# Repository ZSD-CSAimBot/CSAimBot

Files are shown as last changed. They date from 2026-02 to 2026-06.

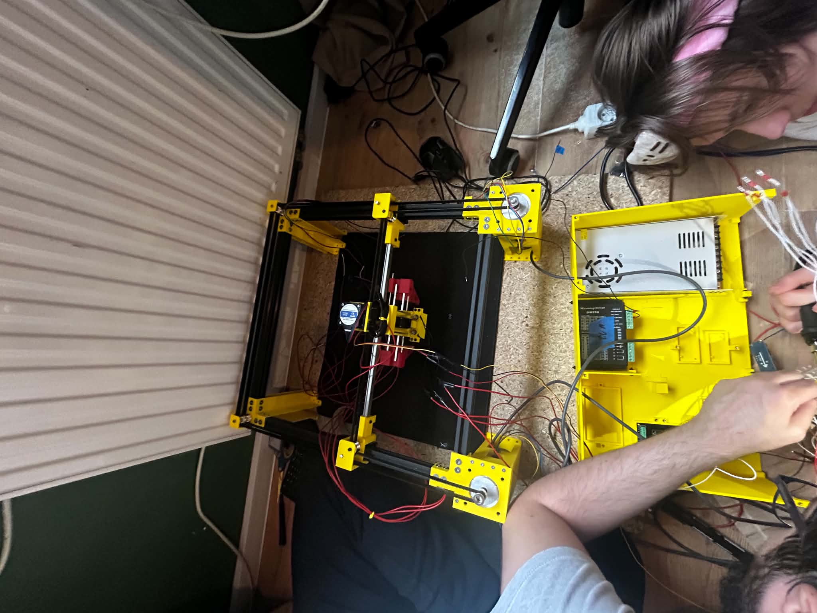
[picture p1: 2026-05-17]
docs/assembly_media/05.15/5d69896e-32a7-49aa-bc5d-4ff8ce60f4f2.jpg

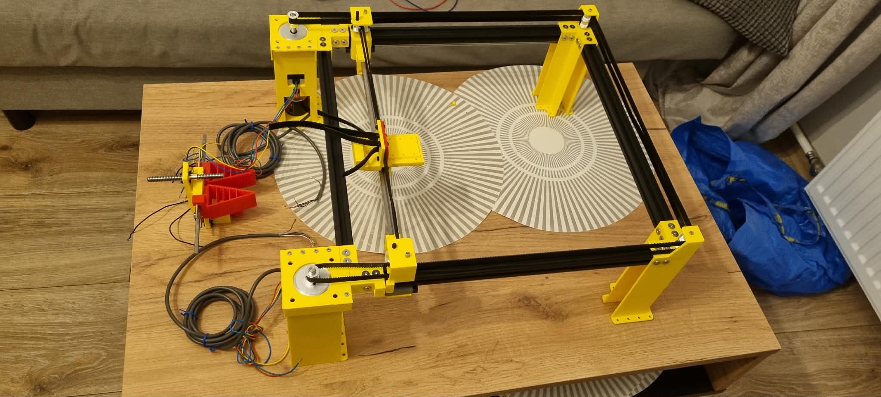
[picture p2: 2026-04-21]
docs/assembly_media/04.11/2.jpg

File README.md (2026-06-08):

# CSAimBot [CSBot]

---

## Brief Project Description
The goal of the project is to create a physical AimBot for the game CS:GO. The program would read the game screen, mark enemies, and return the value by which the mouse must move. To execute the mouse movement, a Cartesian robot with an appropriate grip will be created. The robot would be able to adapt to different mice and DPI values. The robot will be capable of shooting and compensating for weapon recoil, ensuring greater accuracy. The player would control the movement using the WASD keys, so the robot must cooperate with them.

---

## Functional Scope
* Reading the screen and marking enemies.
* Calculating the robot's trajectory.
* Moving the mouse using the Cartesian robot and shooting via a button.
* Looking around if no enemies are detected.
* Cooperating with the player.

---

## System Architecture
* **Robot moving the mouse:** A Cartesian robot featuring stepper motors and encoders or servomechanisms for the XY axes, and a ball/trapezoidal lead screw for the Z axis, equipped with a proper grip capable of holding multiple types of mice. The robot would correct the steering if the crosshair fails to land on the enemy and would compensate for weapon recoil.
* **Screen capture system:** Screen capture will be handled using appropriate Python/C++ libraries, forwarding the captured frames to the enemy detection algorithm.
* **Enemy detection system:** A YOLO-based system will detect and mark enemies on the image, returning values that allow controlling the robot's motors in order to aim at and eliminate the target.

---

## Technology Stack

**Hardware - robot:**
* ESP32 microcontroller, motor drivers.
* NEMA 23 stepper motors, ball/trapezoidal lead screw.
* Power supply, step-down converters.
* 3D printed robot arm and gripper, servo to operate the gripper.

**Hardware - PC:**
* PC with a graphics card, monitor, mouse, keyboard.

**Software:**
* Python/C/C++ languages and relevant libraries, YOLO.
* PyCharm, Arduino IDE, VSC.
* Serial communication (e.g., UART, TCP/IP, USB).
* Inverse kinematics algorithms.

---

## Main Assumptions

### Hardware Assumptions
* The project will operate at room temperature in an enclosed room on a horizontal, flat surface that allows for the proper mounting of the robot (e.g., a desk) and the proper use of the keyboard.
* The mouse will move on a cloth mousepad.
* The mouse must use a laser or optical sensor and have at least 2 buttons (left and right); the remaining buttons will be ignored. 
* When changing the mouse or DPI values, a semi-automatic calibration procedure will be executed. The robot will check the distance it needs to move to transition between reference points on a dedicated map.
* PC-to-Microcontroller communication will be handled via UART (USB) at a baud rate of 115200.

### Software Assumptions
* The computer program will run on Windows 11 Pro build >=25H2 or equivalent. The program will not work on Linux or macOS.
* A PC with adequate computing power is required (a graphics card supporting CUDA, min. RTX 3060) along with a monitor; laptops are not supported.
* The program will detect enemy models in the game (it will distinguish CT models from T models).
* The program will detect whether the user is holding a pistol or a rifle using classic computer vision (template matching with OpenCV). If the player is holding a pistol or a sniper rifle, recoil compensation will be disabled. Otherwise, the program will correct the recoil for specific weapons (AK47/M4A1).

### Game Assumptions
* The program will only run during an active round, on any map.
* The game must run at a minimum of 60 FPS. Enabling the option for instant corpse removal after a kill in a local game is required.
* The reaction time, with the eDPI adjusted so that the robot does not need to lift the mouse, will be at most equal to the reaction time of a skilled player (<200ms).

---

## Project Team
* Tomasz Nazar
* Filip Pietrzak
* Patryk Polechoński
* Hubert Czarnecki
* Karol Puczyński
* Piotr Rokita
* Łukasz Mroczek
* Antoni Sulkowski
* Andrzej Placek
* Łukasz Orluk

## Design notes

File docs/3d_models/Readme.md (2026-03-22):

Nagrywanie_2026-03-15_012706

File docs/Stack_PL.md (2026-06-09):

# Stack Technologiczny

<h2>Software</h2>

- PyCharm >=2025.3.2
- Visual Studio Code >=1.108
- Arduino IDE >=2.3.5
- Python >=3.12
- YOLO26
- Docker + ROS image
- GitHub + Git
- CS:GO - oficjalna wersja legacy
- Autodesk Fusion
- Gazebo
- Bambu Studio

<h2>Hardware</h2>

- Esp32
- 2x silniki NEMA 23
- 3x sterowniki silników krokowych DM556
- Prowadnice
- Szyny
- Śruba kulowa/trapezowa
- Silnik NEMA 17
- Solenoid
- Logic level converter 3.3V -> 5V
- Zasilacz 36V 10A
- Filament TPU
- Filament PLA/PETG
- Kable
- Nvidia RTX 3060

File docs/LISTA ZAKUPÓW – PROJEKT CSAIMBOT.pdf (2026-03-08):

LISTA ZAKUPÓW – PROJEKT CSAIMBOT

I. MECHANIKA
- Szyna liniowa MGN12 z wózkiem (40 cm) – 2 szt.
- Szyna liniowa MGN12 z wózkiem (50 cm) – 1 szt.
- Profil aluminiowy T-slot 2020 (40 cm) – 4 szt.
- Narożniki aluminiowe (wersja 20) – 10 szt.
- Pas zębaty GT2 (5 m, 10 mm szerokości) – 1 szt.
- Rolki zębate GT2 – 6 szt.
- Rolki gładkie GT2 – 2 szt.
- Zębatki napędowe na wał silnika 8 mm – 2 szt.
- Śruba trapezowa osi Z (skok 2 mm, 10 cm) – 1 szt.
- Sprzęgło 8x5 mm – 1 szt.
- Pręt stalowy 3 mm (długość 330 mm) – 2 szt.
- Filament (TPU, 1,75mm, 1 kg) – 1 szt.

II. SILNIKI I STEROWNIKI

- Silnik krokowy Nema 23 (dwustronny wał 8 mm) – 2 szt.
- Silnik krokowy Nema 17 "Pancake" – 1 szt.
- Sterownik cyfrowy DM556 – 3 szt.
- Enkoder obrotowy E6B2-CWZ6C (600 P/R) – 2 szt.

III. CHWYTAK I KLIKANIE

- Serwo MG996R (180 stopni) – 1 szt.
- Zębatka serwa 25T (Moduł 0.5) – 1 szt.
- Listwa zębata (Moduł 0.5, 5x5x300mm) – 1 szt.
- Solenoidy 12V – 2 szt.

IV. ELEKTRONIKA I STEROWANIE

- Mikrokontroler ESP32 – 1 szt.
- Konwerter poziomów logicznych TXS0108E (8-kanałowy) – 1 szt.

- Przetwornica LM2596 ADJ (Regulowana) – 2 szt.
V. ZASILANIE
- Zasilacz (36V, 10A, 360W) – 1 szt.

Wszystkie elementy wymienione w powyższym zestawieniu zostały już zakupione i opłacone.

- Wiele pozycji na liście zostało zamówionych w ilościach większych, niż wynika to z bezpośrednich potrzeb konstrukcyjnych. Wynika to z charakteru pakowania tych elementów, co jednocześnie zapewnia nam zapas w razie awarii lub błędów montażowych.
- Zamówienia zostały rozdzielone pomiędzy różnych dostawców w celu optymalizacji kosztów oraz dostępności. Wykorzystano platformy: Temu, AliExpress, Allegro oraz Poltech.
- Łączny koszt wszystkich podzespołów mechanicznych, napędowych oraz elektronicznych wraz z dostawą wyniósł 1415,50 zł.

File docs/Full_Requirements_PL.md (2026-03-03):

# Zakres funkcjonalny
- Czytanie ekranu
- Oznaczanie przeciwników
- Obliczanie drogi robota
- Ruch myszką za pomocą robota kartezjańskiego
- Strzał za pomocą przycisku
- Rozglądanie się w przypadku braku wykrycia przeciwników
- Współpraca z graczem
- Symulacja robota przez ROS i Gazebo

# Szczegółowe założenia

<h3>Hardware'owe</h3>

- Projekt będzie działać w temperaturze pokojowej w zamkniętym pomieszczeniu na jednolitej poziomej płaskiej powierzchni umożliwiającej poprawne zamontowanie robota (np. biurko) i umożliwiającej poprawne użycie klawiatury.
- Robot będzie rozmiarów umożliwiających swobodne sterowanie myszką i wygodnie sterowanie klawiaturą przez użytkownika na jednym stanowisku.
- Mysz, będzie się poruszać na materiałowej podkładce do myszy.
- Komputer i robot, będą pobierały zasilanie z sieci 230V. Dalsze etapy zasilania (np. zasilacz komputerowy), realizowane w zależności od zastosowanego sprzętu.
- Wszystkie komponenty muszą być sprawne, aby projekt działał poprawnie.
- Pozycja silników krokowych będzie odczytywana z enkoderów podłączonych w odpowiedni sposób do silników.
- Mysz użyta do projektu powinna być bezprzewodowa lub powinna mieć kabel o długości zapewniającej swobodną pracę robota.
- Sterowanie robotem będzie odbywać się WYŁĄCZNIE za pomocą klawiatury i/lub myszki oraz dedykowanych przycisków przy robocie
- Mysz musi posiadać przynajmniej 2 przyciski - lewy i prawy przycisk, reszta przycisków będzie ignorowana.
- Mysz musi korzystać z laserowego lub optycznego sensora. Nie może być to mysz kulkowa. Mysz nie może mieć znacznie wystających niestandardowych elementów.
- Przy zmianie myszki/wartości DPI na inną wykonywana będzie półautomatyczna procedura kalibracji. Robot będzie sprawdzał o ile musi się poruszyć, żeby przejść między punktami referencyjnymi na specjalnej mapie.
- Klawiatura będzie obsługiwana przez jednego użytkownika, steruje poruszaniem się postacią klawiszami WSAD
- Projekt nie będzie obsługiwać komend głosowych ani wizji maszynowej do poleceń.
- Chwytak będzie zamykany serwomechanizmem
- Mysz będzie trzymana siłą tarcia
- Mysz pod chwytakiem robota umieszcza użytkownik w miejscu do tego przeznaczonym (centrum podkładki).
- Nastawy robota będą mogły być zmienione w przypadku poluzowania się części lub wykrycia innych nieprawidłowości.
- Gracz ma do dyspozycji przycisk zatrzymania robota.
- Komunikacja PC-Mikrokontroler poprzez UART (USB) z prędkością 115200 baud
- Przyciski myszy będą naciskane solenoidami lub szybkimi serwomechanizmami.
- Mysz musi mieć klawisze (lewy i prawy) równoległe do powierzchni na której stoi robot. Nie obsługiwane będą myszy typu Logitech MX Vertical itp. 
- Akceleracja wskaźnika myszy jest wyłączona.
- Elementy robota oprócz silników, szyn, sterowników, prowadnic, śrub, zębatek, pasów itp. będą wydrukowane 3d

<h3>Software'owe</h3>

- Program komputerowy będzie działać na systemie Windows 11 Pro build >=25H2 lub równoważnym systemie Windows. Program nie będzie działać na Linuxie ani na MacOS.
- Stworzony zostanie własny dataset do wykrywania przeciwników oraz rodzaju trzymanej broni
- Program będzie działać na komputerze PC o odpowiedniej mocy obliczeniowej (min. karta graficzna RTX 3060) z monitorem - nie na laptopie. Na laptopie może nie zostać spełniony warunek czasu reakcji.
- Program będzie wykrywać modele przeciwników w grze. (Będzie odróżniał modele CT od T)
- Program będzie współpracować z CS:GO w wersji umożliwiającej dodanie botów lub graczy do gry.
- Program będzie komunikował się z robotem za pomocą połączenia przewodowego.
- Program będzie przystosowany do działania lokalnie na komputerze na którym zostanie zainstalowany.
- Ewentualny interfejs użytkownika będzie zrealizowany w języku angielskim.
- Jeśli gracz trzyma pistolet lub karabin snajperski to kompensacja odrzutu będzie wyłączona. W przeciwnym wypadku program będzie korygował odrzut konkretnych broni (AK47/M4A1).
- Podczas celowania z karabinu snajperskiego wykrywani zostaną tylko wrogowie znajdujący się w polu widzenia lunety. Włączeniem / Wyłączeniem przybliżenia steruje użytkownik z klawiatury.
- Użytkownik będzie używał praworęcznego modelu broni.
- Robot będzie strzelał pojedynczymi strzałami lub seriami w zależności od ustawienia gracza. Odrzut będzie kompensowany jedynie przy strzelaniu seriami.
- Program będzie działał z grą ustawioną na minimum 60 FPS.
- Okno wykrywania będzie miało rozmiar 1280x736
- Robot będzie miał 100% celności w cele statyczne.
- Robot będzie miał 60% celności w cele poruszające się.
- Trenowanie YOLO - na komputerze 
- Rozdzielczość 1080p
- ROS obsługiwany za pomocą Dockera i WSL2 na Windows

<h3>Związane z grą</h3>

- Program będzie działał tylko podczas rozpoczętej rundy.
- Program będzie działał na dowolnej oficjalnej mapie CS:GO
- Program będzie działał z włączoną opcją natychmiastowego usuwania ciał po zabójstwie w grze lokalnej
- W przypadku wykrycia kilku celów, program wybiera cel najbliżej aktualnej pozycji celownika
- Czas reakcji przy eDPI dobranym tak, aby robot nie musiał podnosić myszy będzie wynosił maksymalnie tyle ile czas reakcji dobrego gracza (<200ms) Czasem reakcji nazywamy czas po którym robot zaczyna kierować mysz w stronę przeciwnika od jego pojawienia się na ekranie.
- Viewmodel będzie ustawiony tak aby było go widać w obszarze przechwytywania

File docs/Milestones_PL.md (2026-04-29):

# Milestones

---

## Milestone 1: Wstępny model i projekt sprzętowy
### M1 - Software (Wykrywanie w YOLO):

* **Cel**: Przetwarzanie obrazu i lokalizacja przeciwników na ekranie, komunikacja z mikrokontrolerem.

* **Mierzalny wskaźnik**: Średnia precyzja, szybkość przetwarzania (FPS) oraz rozmiar datasetu.

* **Dataset / Sposób pomiaru**: Ewaluacja na zbiorze testowym złożonym ze screenów z gry na różnych mapach z użyciem wbudowanych skryptów YOLO. Prędkość mierzona podczas gry lokalnej.

* **Warunek przejścia dalej**: Skuteczność YOLO > 80% dla wykrywania modeli CT/T, stałe utrzymanie min. 60 FPS w czasie inferencji na karcie RTX 3060, dataset o rozmiarze min 5000 zdjęć.

### M1 - Hardware (Projekt CAD):

* **Cel**: Zaprojektowanie robota kartezjańskiego zdolnego do przemieszczania i podnoszenia myszki oraz przygotowanie kosztorysu

* **Mierzalny wskaźnik**: Osiągalna przestrzeń robocza oraz teoretyczny luz mechaniczny.

* **Sposób pomiaru**: Symulacja kinematyki i pomiary w programie typu CAD (np. Autodesk Fusion).

* **Warunek przejścia dalej**: Projekt pozwala na pełne pokrycie wirtualnej podkładki o wymiarach min. 30x30 cm, podniesienie uchwytu z myszką w osi Z na wysokość gwarantującą brak odczytu sensora oraz zakupienie części.
---

## Milestone 2: Konstrukcja i sterowanie ręczne
### M2 - Software (Aplikacja i integracja wejścia):

* **Cel**: Aplikacja PC czytająca klawiaturę i wysyłająca komendy do mikrokontrolera, symulacja w Gazebo, kompensacja odrzutu broni.

* **Mierzalny wskaźnik**:Opóźnienie przesyłu danych (Latency) na linii PC -> Mikrokontroler. Rozmiar datasetu oraz skuteczność Yolo. 

* **Sposób pomiaru**: Analiza logów z timestampami wysłania paczki danych oraz potwierdzenia jej odbioru przez UART (115200 baud).

* **Warunek przejścia dalej**: Skuteczność YOLO > 95%, opóźnienie wysłania pakietu poniżej 5 ms i ~0% zgubionych ramek na dystansie 10 tysięcy prób, dataset o rozmiarze min 10000 zdjęć. 

### M2 - Hardware (Fizyczny robot):

* **Cel**: Budowa fizycznego robota i weryfikacja poprawności sterowania silnikami z poziomu aplikacji.

* **Mierzalny wskaźnik**: Czas reakcji mechaniki na komendę.

* **Sposób pomiaru**: Nagranie w zwolnionym tempie od momentu wciśnięcia przycisku klawiatury do rozpoczęcia ruchu silnika krokowego/serwa.

* **Warunek przejścia dalej**: Wydrukowane elementy 3D, reakcja silników i fizyczne poruszenie myszką. Czas reakcji<200ms.
---

## Milestone 3: Pełna integracja (Auto-Aim i kalibracja)
### M3 - Software + Hardware:

* **Cel**: Integracja całego systemu: YOLO podaje koordynaty, algorytm przelicza je na kroki, a robot fizycznie namierza i strzela.

* **Mierzalny wskaźnik**: Całkowity czas reakcji układu, celność strzału oraz skuteczność wykrywania broni po stronie gracza.

* **Sposób pomiaru**: Testy na lokalnym serwerze treningowym (np. Aim Botz). Mierzenie poprzez analizę nagrania z rozgrywki.

* **Warunki przejścia dalej**:

* Całkowity czas reakcji układu (Wykrycie -> Ruch) wynosi < 200 ms.

* Dokładność namierzania stojącego celu 100%.

* Półautomatyczna procedura kalibracji eDPI/myszki działa poprawnie.

* System poprawnie włącza/wyłącza kompensację odrzutu na podstawie trzymanej broni (AK47/M4A1 vs Pistolet/Snajperka).

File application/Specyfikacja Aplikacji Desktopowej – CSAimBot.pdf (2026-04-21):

# Specyfikacja Aplikacji Desktopowej – CSAimBot

## 1. Wymagania Funkcjonalne Aplikacji

a. Moduł Komunikacji

Moduł ten odpowiada za ustanowienie, utrzymanie i monitorowanie stabilnego, dwukierunkowego połączenia między komputerem PC a mikrokontrolerem zarządzającym sprzętem, a także za obsługę środowiska symulacyjnego:

- Nawiązywanie Połączenia
- Wygląd (UI): Główny przycisk "Połącz / Rozłącz", inicjujący komunikację. Etykieta przycisku zmienia się dynamicznie w zależności od aktualnego stanu.
- Zasada działania (Backend): Po wciśnięciu przycisku otwierana jest komunikacja PC-Mikrokontroler poprzez UART (USB). Następuje utworzenie połączenia między komputerem, a mikrokontrolerem. W tle realizowana jest procedura nawiązywania połączenia – aplikacja PC wysyła ramkę testową (np. INIT_CSBOT), a mikrokontroler musi odpowiedzieć z góry zdefiniowanym potwierdzeniem. Zabezpiecza to przed przypadkowym wysłaniem komend ruchu do innego urządzenia podpiętego pod USB.
- Status Połączenia i Monitorowanie Logów
- Wygląd (UI): Wizualny wskaźnik (np. dioda LED w interfejsie: Zielona = połączono, Czerwona = błąd) informujący o poprawnym połączeniu lub błędzie.
- Zasada działania (Backend): Obsługa komunikacji działa w osobnym wątku aplikacji (tzw. Thread/Worker), aby nasłuchiwanie na porcie nie blokowało interfejsu graficznego użytkownika.
- Przełącznik Trybu Pracy (Fizyczny / Symulacja)
- Wygląd (UI): Przełącznik typu Toggle lub osobne zakładki pozwalające wybrać między pracą na fizycznym urządzeniu ("Tryb Sprzętowy") a symulacją ("Tryb ROS").
- Zasada działania (Backend): Moduł obsługuje komunikację Windows -> ROS na dockerze. Po aktywacji tego trybu, wyliczone z systemu wizyjnego wektory ruchu nie są wysyłane na port UART, lecz przekierowywane (np. poprzez protokół TCP/UDP) do kontenera, co pozwala na symulację robota w Gazebo. Środowisko to wspiera również pełny obieg danych, włączając w to komunikację ROS->(Windows)->Robot, jeśli wymagana będzie integracja sprzętowa w pętli symulacji.

b. Moduł Kalibracji i Diagnostyki

Sekcja niezbędna do przygotowania robota do pracy z różnymi modelami myszy i ustawieniami systemowymi:

- Bazowanie (Homing):
- Wygląd (UI): Przycisk "Bazuj robota (HOME)". Obok znajdują się kontrolki stanu osi X oraz Y (np. czerwone ikony zmieniające się na zielone po udanym bazowaniu) oraz tekstowe wyświetlanie aktualnych współrzędnych maszynowych.
- Flow użytkownika: Po uruchomieniu urządzenia użytkownik musi kliknąć ten przycisk, zanim podejmie jakąkolwiek inną akcję. Opcjonalnie program może wymuszać tę akcję przy każdym nowym połączeniu z portem szeregowym.
- Zasada działania (Backend): Po wciśnięciu przycisku aplikacja wysyła dedykowaną ramkę danych (np. komendę HOME) przez UART do mikrokontrolera. Mikrokontroler zaczyna podawać impulsy na sterowniki silników krokowych osi X i Y, wymuszając ruch wózka w kierunku punktu zerowego. Następnie wysyłany jest sygnał przerwania (interrupt) do mikrokontrolera, który natychmiast zatrzymuje silniki i przypisuje tej pozycji wartość X=0, Y=0. Od tego momentu aplikacja wie, gdzie znajduje się środek podkładki i jaki jest maksymalny bezpieczny zakres ruchu.
- Kalibracja DPI:
- Wygląd (UI): Przycisk "Rozpocznij Kalibrację".
- Flow użytkownika: Uruchamiana jest specjalna mapa w CS:GO z punktami referencyjnymi. Użytkownik ustawia mysz na środku obszaru roboczego i uruchamia proces.
- Zasada działania (Backend): Algorytm musi ustalić relację między fizycznym ruchem myszy a ruchem celownika na ekranie. Robot będzie sprawdzał, o ile musi się poruszyć, żeby przejść między punktami referencyjnymi na specjalnej mapie. W tym celu przewidujemy wykorzystanie dokładnie trzech stałych punktów referencyjnych (np. tworzących trójkąt w przestrzeni gry). Aplikacja wysyła do robota rozkaz przesunięcia się w stronę każdego z tych punktów o ściśle określoną, znaną odległość (np. określoną liczbę kroków silnika). Robot wykonuje ruch, a następnie system wizyjny przechwytujący ekran analizuje przesunięcie celownika względem tych trzech punktów. Wiedząc, o ile kroków obróciły się silniki w obu osiach podczas przejścia między poszczególnymi punktami i o ile pikseli przesunął się obraz, aplikacja oblicza bardzo precyzyjny współczynnik proporcjonalności. Dzięki temu podczas właściwej gry, gdy YOLO wykryje głowę przeciwnika w odległości 60 pikseli, aplikacja błyskawicznie przeliczy to na konkretną liczbę kroków do wysłania do sterowników silników.

- Mapa kalibracyjna:

Komenda w terminalu dla CSGO:

steam.exe -applaunch 730 +map nazwa_mapy -insecure

- -applaunch 730: Informuje Steama, że chcemy włączyć CS:GO.
- +map nazwa_mapy: Zmusza grę do natychmiastowego załadowania konkretnej mapy z folderu csgo/maps/ z pominięciem głównego menu.
- -insecure: Uruchamia grę bez ochrony VAC (Valve Anti-Cheat). Blokuje ona możliwość wejścia na serwery publiczne, eliminując ryzyko nałożenia blokady na konto użytkownika podczas testów.

Użycie wbudowanej biblioteki subprocess, która będzie podłączona z przyciskiem "Rozpocznij Kalibrację" w aplikacji.

Kod windows:

import subprocess
import os

def uruchom_kalibracje():
steam_path = r"C:\Program Files (x86)\Steam\steam.exe" map_name = "aimbot_calibration_map"

command = [
steam_path,
"-applaunch", "730", | # ID gry
"+map", map_name, | # Załaduj mapę
"-insecure", | # Wyłącz VAC
"-windowed", "-w", "1920", "-h", "1080" # Wymuś okno i rozdzielczość ]

try:
print("Uruchamianie CS:GO z mapą kalibracyjną...") subprocess.Popen(command)
except Exception as e:
print(f"Błąd podczas uruchamiania: {e}")

### 2. Kod w Pythonie (Wersja Linux)

import subprocess

def uruchom_kalibracje_linux():
map_name = "aimbot_calibration_map"

command = [
"steam",
"-applaunch", "730", | # ID gry
"+map", map_name, | # Załaduj mapę
"-insecure", | # Wyłącz VAC
"-windowed", "-w", "1920", "-h", "1080" # Wymuś okno i rozdzielczość ]

try:
print("Uruchamianie CS:GO na Linuxie z mapą kalibracyjną...") subprocess.Popen(command)
except FileNotFoundError:
print("Błąd: Nie znaleziono wykonywalnego pliku 'steam'.") except Exception as e:
print(f"Błąd podczas uruchamiania: {e}")
- Test chwytaka i klikacza:
- Wygląd (UI): Panel diagnostyczny zawierający przyciski "Zaciśnij / Zwolnij Chwytak" oraz przyciski wyzwalające lewy (LPM) i prawy (PPM) przycisk myszy. Warto dodać suwak do precyzyjnej regulacji siły docisku, aby nie zgnieść obudowy myszki.
- Flow użytkownika: Użytkownik wykorzystuje ten panel do wstępnego ustawienia robota po umieszczeniu nowej myszki.
- Zasada działania (Backend):
a) Chwytak: Aplikacja wysyła docelową wartość wychylenia. Mikrokontroler przekłada tę wartość na sygnał PWM (Pulse Width Modulation) o odpowiednim wypełnieniu, wysyłany do serwomechanizmu. Serwo obraca orczyk, zamykając wydrukowany z TPU chwytak, który utrzymuje mysz siłą tarcia.
b) Klikacz: Zgodnie ze specyfikacją, do naciskania klawiszy użyte będą solenoidy. Po kliknięciu "Test LPM" w aplikacji, program wysyła krótką komendę uderzenia. Mikrokontroler wysyła pojedynczy, bardzo krótki impuls prądowy na cewkę solenoidu. Pole magnetyczne błyskawicznie wypycha rdzeń z odpowiednią siłą, fizycznie wciskając przycisk myszy leżącej pod robotem, po czym rdzeń wraca do pozycji spoczynkowej.
c. Moduł Bezpieczeństwa

Ten moduł odpowiada za ochronę sprzętu (robota, komputera i urządzeń peryferyjnych) przed uszkodzeniami mechanicznymi oraz za zachowanie kontroli użytkownika nad pracą urządzenia w sytuacjach awaryjnych.

- Awaryjne Zatrzymanie (E-Stop)
- Wygląd (UI): Czerwony przycisk "E-STOP / ZATRZYMAJ". Dodatkowo, w ustawieniach aplikacji musi istnieć możliwość przypisania globalnego skrótu klawiszowego (np. Spacja lub Escape), który zadziała nawet wtedy, gdy aplikacja zminimalizowana jest w tle podczas gry w CS:GO.
- Flow użytkownika: Gracz ma do dyspozycji przycisk zatrzymania robota. W przypadku nagłego, niekontrolowanego ruchu ramienia lub zablokowania mechanizmu, gracz uderza w zaprogramowany klawisz. Robot natychmiast zatrzymuje się w miejscu, a w aplikacji pojawia się komunikat o trybie awaryjnym.
- Zasada działania (Backend): Aplikacja wymusza natychmiastowe wysłanie priorytetowej ramki danych (np. komendy HALT) przez interfejs UART. Mikrokontroler odbiera tę komendę jako przerwanie o najwyższym priorytecie. Logika sprzętowa natychmiast przestaje generować sygnały krokowe (STEP/DIR) dla sterowników silników. Dodatkowo, mikrokontroler wysyła sygnał dezaktywujący (np. pin ENABLE na sterownikach silników krokowych), co zdejmuje moment trzymający z cewek silników. Dzięki temu wózek osi X/Y traci sztywność i gracz może bezpiecznie, ręcznie odsunąć ramię robota od myszki bez ryzyka uszkodzenia napędów.
- Monitorowanie Integralności i Zgubionych Kroków - opcjonalne
- Wygląd (UI): Panel wskaźników statusu (np. zielone/czerwone kropki) dla każdej osi z osobna (X, Y, Z). W razie awarii pojawia się pop-up z dokładnym kodem błędu (np. Błąd pozycjonowania osi X - zablokowany wózek). W panelu znajduje się również dostęp do zmiany parametrów robota.
- Flow użytkownika: Jeśli podczas pracy robot nagle uderzy w przeszkodę i zgubi kroki, aplikacja automatycznie przerwie jego pracę, aby nie pogorszyć sytuacji. Nastawy robota będą mogły być zmienione w przypadku poluzowania się części lub wykrycia innych nieprawidłowości. Użytkownik musi wtedy zweryfikować stan mechaniczny, dokręcić elementy i przeprowadzić ponowne bazowanie.
- Zasada działania (Backend): Algorytm opiera się na sprzężeniu zwrotnym z układu napędowego. Pozycja silników krokowych będzie odczytywana z enkoderów podłączonych w odpowiedni sposób do silników. Mikrokontroler nieustannie porównuje zadaną pozycję z faktyczną. Jeśli różnica między tymi wartościami przekroczy bezpieczny próg błędu, system wnioskuje, że wystąpiła fizyczna blokada lub przeciążenie. Aplikacja natychmiast uruchamia procedurę E-Stop, ponieważ wszystkie komponenty muszą być sprawne, aby projekt działał poprawnie.
d. Moduł Statystyk i Monitorowania

Sekcja analityczna pełni rolę narzędzia diagnostycznego oraz walidacyjnego. Jej głównym zadaniem jest ciągłe zbieranie danych telemetrycznych i wizyjnych w celu weryfikacji, czy fizyczny układ (robot + system wizyjny) spełnia rygorystyczne założenia projektowe dotyczące czasu reakcji i celności:

- Monitorowanie Czasu Reakcji
- Wygląd (UI): Dynamiczny wykres liniowy (odświeżany w czasie rzeczywistym) pokazujący opóźnienia w milisekundach. Obok wykresu znajdują się liczniki: "Aktualny czas reakcji", "Średni czas reakcji" oraz wskaźnik wizualny (np. zielony/czerwony), który zapala się na czerwono, gdy opóźnienie przekroczy założone w projekcie maksimum (<200 ms).
- Flow użytkownika: Użytkownik nie musi aktywnie ingerować w ten panel podczas gry. Po zakończeniu rundy lub meczu może wejść w tę zakładkę, aby sprawdzić czas reakcji.
- Zasada działania (Backend): Aplikacja precyzyjnie loguje znaczniki czasu (timestamps) w trzech kluczowych momentach trwania pętli sterowania:
a) T1 (Detekcja): Moment, w którym algorytm YOLO z sukcesem zidentyfikuje przeciwnika (bounding box) i zaklasyfikuje go jako priorytet (np. najbliżej celownika).
b) T2 (Transmisja): Moment wysłania przeliczonego wektora ruchu przez port UART do mikrokontrolera.
c) T3 (Akcja sprzętowa): Moment odebrania przez PC sprzętowego potwierdzenia od mikrokontrolera, że pierwsze impulsy zostały wysłane na sterowniki silników.
Całkowity czas reakcji układu to różnica między T3 i T1. Aplikacja uśrednia te wyniki, by zniwelować błędy pomiarowe.
- Skuteczność i Celność
- Wygląd (UI): Panel w formie "Dashboardu" zawierający wskaźniki procentowe (np. wykresy). Podzielony na dwie główne kategorie: "Celność – Cele Statyczne" oraz "Celność – Cele Poruszające się". Widoczny jest też ogólny licznik oddanych strzałów do strzałów trafionych.
- Flow użytkownika: Gracz może przeglądać skuteczność w poprzednich rozgrywkach.

- Zasada działania (Backend): Jest to jeden z bardziej zaawansowanych mechanizmów aplikacji, opierający się na analizie klatek z gry:
a) Rozpoznawanie ruchu celu: System analizuje zmianę pozycji tzw. "bounding boxa" przeciwnika między kolejnymi klatkami obrazu. Jeśli środek ramki pozostaje w tym samym miejscu (z uwzględnieniem drobnego marginesu błędu), cel uznawany jest za statyczny. Jeśli ramka wyraźnie przesuwa się po osi X/Y, cel traktowany jest jako poruszający się.
b) Weryfikacja trafienia: Aplikacja zlicza każdą komendę aktywacji klikacza (solenoidu) wysłaną do robota. Następnie, system wizyjny analizuje np. pojawienie się czerwonego markera trafienia (w przypadku włączonych odpowiednich wskaźników w grze) lub analizuje killfeed w prawym górnym rogu ekranu, aby potwierdzić eliminację. Wynik jest zapisywany w odpowiedniej kategorii (cel ruchomy/statyczny).
- Zapis i Eksport Danych - opcjonalne
- Wygląd (UI): Przycisk "Eksportuj raport sesji (CSV/JSON)" oraz tabela wyświetlająca historię zapisanych meczów.
- Flow użytkownika: Użytkownik pobiera plik w celu analizy danych i wygenerowania wykresów.
- Zasada działania (Backend): Program działający w tle zapisuje do lokalnej, lekkiej bazy danych lub pliku tekstowego kluczowe parametry użyte w danej sesji: użyte DPI, aktualny współczynnik kalibracji pikseli na kroki silnika, rodzaj używanej broni odczytanej przez YOLO oraz zebrane logi skuteczności i czasu reakcji.

## 2. Research Technologiczny

a. Wybór frameworka GUI: Porównanie Tkinter vs. PyQt

Projekt CSAimBot narzuca rygorystyczne wymagania architektoniczne. Aplikacja okienkowa musi w czasie rzeczywistym integrować trzy wymagające procesy: analizę obrazu przez model sztucznej inteligencji (YOLO), nieprzerwaną dwukierunkową komunikację sprzętową (UART z mikrokontrolerem) oraz dynamiczne renderowanie interfejsu użytkownika.

Ze względu na to, że rdzeń logiczny i wizyjny systemu zaimplementowano w języku Python, podjęto decyzję o realizacji interfejsu graficznego w tym samym środowisku, aby wyeliminować opóźnienia wynikające z komunikacji międzyprocesowej (IPC). W ramach researchu przeanalizowano i zestawiono ze sobą dwa główne podejścia: bibliotekę Tkinter (wraz z nowoczesnym forkiem CustomTkinter) oraz framework PyQt6.

- Biblioteka Tkinter

Tkinter to domyślna biblioteka graficzna wbudowana w standardową dystrybucję języka Python. Jej standardowy, surowy wygląd można unowocześnić za pomocą zewnętrznej biblioteki CustomTkinter, która wprowadza nowoczesne elementy interfejsu.

Zalety:

- Brak konieczności instalacji złożonych zależności: Tkinter działa "out-of-the-box" na każdej instalacji Pythona, co znacznie upraszcza proces dystrybucji i pakowania aplikacji.
- Niskie zapotrzebowanie na zasoby: Aplikacje napisane w tym środowisku uruchamiają się błyskawicznie i zużywają minimalne ilości pamięci RAM, co pozostawia więcej zasobów dla obciążającego modelu YOLO.

Ograniczenia:

- Brak natywnego bezpieczeństwa wątkowego (Not thread-safe): Jest to istotne wyzwanie z perspektywy naszego projektu. Biblioteka źle znosi modyfikacje interfejsu z poziomu innych wątków. Równoległe uruchomienie ciągłego nasłuchiwania portu UART, pętli YOLO i interfejsu graficznego za pomocą standardowej biblioteki threading stwarza ryzyko "zamrażania" okna aplikacji.
- Wydajność multimedialna: Osadzanie dynamicznych, szybko odświeżających się strumieni wideo (klatki z OpenCV) oraz renderowanie płynnych wykresów w czasie rzeczywistym wymaga stosowania nieoptymalnych obejść i mocno obciąża główną pętlę programu.
- Framework PyQt6

PyQt6 to pythonowy port frameworka Qt, opierającego się na języku C++. Jest to rozwiązanie stosowane powszechnie w przemyśle do tworzenia zaawansowanego oprogramowania, w tym systemów sterowania maszynami.

Zalety:

- Rozbudowana architektura wielowątkowości: Framework posiada natywne, bardzo stabilne rozwiązanie problemu wielowątkowości (QThread). Wątki poboczne mogą bezkolizyjnie wymieniać dane z głównym wątkiem GUI za pomocą asynchronicznego mechanizmu Sygnałów i Slotów, co gwarantuje pełną responsywność interfejsu nawet pod dużym obciążeniem.

- Graficzne środowisko projektowe: Dostępność narzędzia Qt Designer pozwala na wizualne projektowanie układu okien i ich bezproblemowy eksport do kodu Pythona.
- Wysoka wydajność renderowania: Środowisko jest przystosowane do płynnej obsługi strumieni wideo oraz dynamicznych danych (np. za pomocą zintegrowanych bibliotek do rysowania wykresów).

Ograniczenia:

- Większy rozmiar i złożoność: Biblioteka zajmuje znacznie więcej pamięci niż Tkinter, co przełoży się na większy rozmiar ostatecznego pliku instalacyjnego. Wymaga również pobrania dodatkowych, zewnętrznych paczek przez menedżer pip.
- Wysoki próg wejścia: Zrozumienie specyficznej dla Qt pętli zdarzeń oraz paradygmatu sygnałów i slotów wymaga poświęcenia większej ilości czasu na etapie wdrożenia.
b. Odpalanie CS:GO na Linuxie i system wizyjny

Uruchomienie gry CS:GO na systemie Linux oraz bezpośrednia integracja aplikacji analizującej obraz wymaga uwzględnienia fundamentalnych różnic w architekturze wyświetlania obrazu w porównaniu do systemu Windows.

Środowisko uruchomieniowe gry na Platformie Steam udostępnia w pełni natywnego klienta gry na systemy z rodziny Linux. Oznacza to, że silnik gry komunikuje się bezpośrednio ze sterownikami karty graficznej (wykorzystując API Vulkan lub OpenGL), bez pośrednictwa jakichkolwiek warstw kompatybilności. Z punktu widzenia naszego projektu jest to sytuacja optymalna – natywne wykonanie minimalizuje narzut procesora i pozwala na stabilne utrzymanie założonych w projekcie minimum 60 FPS. Dodatkowo, aby zrealizować wymagania sprzętowe, komputer musi posiadać zainstalowane własnościowe sterowniki (np. NVIDIA) zapewniające obsługę rdzeni CUDA, które są niezbędne dla szybkiej inferencji modelu YOLO.

Jako narzędzie do pobierania klatek wybrano bibliotekę bettercam. O ile na systemie Windows szybkie przechwytywanie pamięci z karty graficznej (np. poprzez DXGI Desktop Duplication) jest natywne i zunifikowane, o tyle na środowisku Linux architektura ta jest znacznie bardziej pofragmentowana i zależy od używanego serwera wyświetlania:

- Środowisko X11 (X.Org Server): Jest to tradycyjny menedżer okien. Z inżynieryjnego punktu widzenia X11 pozwala na stosunkowo łatwy dostęp do głównego bufora ramki (root window). Biblioteki pythonowe do zrzutów ekranu mogą w tym środowisku wykorzystywać rozszerzenie XShm (MIT Shared Memory Extension). Pozwala ono na ominięcie kopiowania danych przez sieć serwera X i bezpośredni odczyt pikseli z pamięci współdzielonej. Gwarantuje to niezwykle niskie opóźnienia, co jest absolutnie kluczowe dla dostarczenia klatek do modelu YOLO w czasie rzeczywistym.

- Środowisko Wayland: Jest to nowoczesny protokół, który został zaprojektowany z myślą o ścisłym bezpieczeństwie i izolacji procesów. Architektura Waylanda domyślnie blokuje aplikacjom trzecim możliwość bezpośredniego czytania pikseli z okien innych aplikacji (czyli CS:GO). Aby przechwycić obraz na Waylandzie, nasza aplikacja musiałaby komunikować się przez złożony system PipeWire oraz interfejsy D-Bus (xdg-desktop-portal). Wprowadza to ogromny narzut technologiczny, wymusza kompresję/dekompresję strumienia i znacząco podnosi opóźnienia.

Głównym założeniem projektu jest utrzymanie całkowitego czasu reakcji robota poniżej 200 ms. Biorąc pod uwagę czas potrzebny na inferencję sieci YOLO oraz transmisję danych przez UART do mikrokontrolera, budżet czasowy na samo przechwycenie klatki jest skrajnie mały.

W związku z tym, wymogiem koniecznym do poprawnego działania aplikacji na systemie Linux jest uruchomienie sesji opartej wyłącznie na serwerze X11. Środowisko Wayland, ze względu na swoje restrykcje bezpieczeństwa i opóźnienia w przechwytywaniu strumienia, całkowicie dyskwalifikuje się w zastosowaniach wymagających milisekundowej precyzji w analizie klatek z gier.

## 3. Tworzenie instalki (.exe i Linux)

W celu udostępnienia aplikacji użytkownikom końcowym, konieczne jest przekształcenie kodu źródłowego w samodzielne pakiety instalacyjne. Do utworzenia pakietów instalacyjnych zostaną użyte dedykowane narzędzia dla poszczególnych platform.

a. Środowisko Windows

Dystrybucja na systemy Windows zostanie podzielona na dwa etapy:

- Budowanie pliku wykonywalnego (.exe): Zastosowane zostanie narzędzie PyInstaller. Skrypt kompilujący użyje flag wymuszających tryb okienkowy (bez konsoli w tle) oraz architekturę katalogową, co jest zalecane przy dużych projektach AI.

Przykładowa komenda w terminalu (Windows):

pyinstaller --noconsole --onedir --name "CSAimBot" --add-data "models/yolo_weights.pt;models/" main.py

(Flaga --add-data gwarantuje, że model sztucznej inteligencji zostanie prawidłowo dołączony do folderu wyjściowego dist/CSAimBot).

- Tworzenie kreatora instalacji: Do utworzenia ostatecznego pakietu instalacyjnego użyte zostanie oprogramowanie Inno Setup. Skrypt pobierze wygenerowane przez PyInstaller pliki binarne i skompresuje je do pliku setup.exe, tworząc niezbędne skróty.

Przykładowy fragment skryptu konfiguracyjnego (CSAimBot_Installer.iss):

[Setup]
AppName=CSAimBot
AppVersion=1.0
DefaultDirName={autopf}\CSAimBot OutputDir=.\Installer
OutputBaseFilename=CSAimBot_Setup

[Files]
; Pobranie całego wygenerowanego folderu z aplikacją
Source: "dist\CSAimBot\*"; DestDir: "{app}"; Flags: ignoreversion recursesubdirs createallsubdirs

[Icons]
; Utworzenie skrótów na pulpicie i w menu Start
Name: "{autodesktop}\CSAimBot"; Filename: "{app}\CSAimBot.exe" Name: "{group}\CSAimBot"; Filename: "{app}\CSAimBot.exe"
b. Środowisko Linux

Tworzenie pakietu na systemy z rodziny Linux wymaga innego podejścia, gwarantującego niezależność od dystrybucji.

- Kompilacja binarki natywnej: Podobnie jak na platformie Windows, kod źródłowy zostanie spakowany przy użyciu narzędzia PyInstaller uruchomionego natywnie w środowisku Linux (np. na systemie Ubuntu).

Przykładowa komenda w terminalu (Linux):

pyinstaller --noconsole --onedir --name "CSAimBot" --add-data "models/yolo_weights.pt:models/" main.py

(Uwaga: w systemie Linux separator ścieżek w --add-data to dwukropek :, w przeciwieństwie do średnika ; w Windowsie).

- Tworzenie pakietu dystrybucyjnego (AppImage): Do utworzenia uniwersalnego pakietu instalacyjnego użyte zostanie narzędzie appimagetool. Wygenerowany wcześniej folder dist/CSAimBot zostanie zintegrowany ze specjalnym plikiem AppRun, który zarządza ścieżkami bibliotek, a następnie spakowany do jednego pliku wykonywalnego.

Przykładowy skrypt powłoki (build_appimage.sh) do automatyzacji procesu:

#!/bin/bash

echo "Kompilacja za pomocą PyInstaller..."
pyinstaller --noconsole --onedir --name "CSAimBot" --add-data "models/yolo_weights.pt:models/" main.py echo "Przygotowanie struktury AppDir..." mkdir -p AppDir/usr/bin
cp -r dist/CSAimBot/* AppDir/usr/bin/

echo "Tworzenie pliku .desktop..."
cat > AppDir/CSAimBot.desktop << 'EOF' [Desktop Entry]
Name=CSAimBot
Exec=CSAimBot
Icon=csaimbot
Type=Application
Categories=Utility;
EOF

echo "Generowanie AppImage..."
chmod +x appimagetool-x86_64.AppImage ./appimagetool-x86_64.AppImage AppDir CSAimBot-x86_64.AppImage

echo "Zakończono! Pakiet AppImage jest gotowy."

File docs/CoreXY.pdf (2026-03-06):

## Dokumentacja Techniczna Mechanizmu CoreXY Projekt CSAimBot

## 1 Wstęp

Projekt CSAimBot stanowi zaawansowane połączenie oprogramowania opartego na wizji maszynowej z fizycznym układem wykonawczym. Poniższa dokumentacja techniczna skupia się wyłącznie na mechanicznej konstrukcji oraz kinematyce układu napędowego robota kartezjańskiego, który stanowi serce całego urządzenia. Opracowanie to szczegółowo opisuje mechanizm płaskiego pozycjonowania (w osiach X i Y), odpowiedzialny za przeniesienie wirtualnych współrzędnych celu na rzeczywisty ruch fizycznej myszy komputerowej.
Głównym zadaniem opisywanego układu jest zapewnienie błyskawicznego, wysoce precyzyjnego i powtarzalnego przesuwania myszy na płaszczyźnie roboczej (np. na podkładce materiałowej). Ze względu na specyfikę gier e-sportowych typu FPS (First-Person Shooter), układ ten musi charakteryzować się parametrami dynamiki dorównującymi, a nawet przewyższającymi możliwości ludzkiej ręki, co stawia przed konstruktorami wyjątkowe wyzwania w zakresie doboru odpowiedniej architektury mechanicznej.

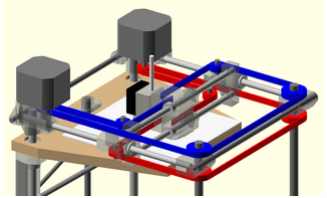
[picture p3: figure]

Rysunek 1: Poglądowy model układu kinematycznego CoreXY, obrazujący stacjonarne osadzenie silników.

## 2 CoreXY - Opis teoretyczny i typowe zastosowanie

CoreXY to wysoce wyspecjalizowany rodzaj kinematyki stosowanej w nowoczesnych maszynach CNC oraz robotach kartezjańskich. Wyróżnia się on tym, że osie X i Y nie posiadają niezależnych, przypisanych do siebie napędów liniowych. Zamiast tego, ruch w płaszczyźnie realizowany jest w oparciu o wspólny, bardzo długi i zapętlony system pasów napędowych, który oplata układ specjalnie rozmieszczonych rolek gładkich i zębatych. W odróżnieniu od tradycyjnych układów kartezjańskich (w których silnik osi Y często podróżuje na wózku osi X, co znacząco zwiększa masę ruchomą), w systemie CoreXY oba silniki napędowe zamontowane są całkowicie stacjonarnie, na nieruchomej ramie zewnętrznej maszyny. Taka architektura sprawia, że całkowita masa ruchomego wózka (tzw. gantry) oraz prowadnic poprzecznych jest zredukowana do absolutnego minimum – porusza się jedynie lekki profil, wózek centralny oraz sam pas napędowy.
Z powodu swojej unikalnej zdolności do minimalizowania inercji przy zachowaniu wysokiej sztywności, kinematyka CoreXY znajduje typowe zastosowanie w bardzo szybkich drukarkach 3D (szczególnie tych o dużej powierzchni roboczej), ploterach laserowych oraz precyzyjnych maszynach montażowych typu pick-and-place. Jest to optymalny wybór wszędzie tam, gdzie kluczowym parametrem jest wysoka dynamika pracy, konieczność osiągania ogromnych przyspieszeń oraz absolutny brak drgań przy gwałtownych zmianach kierunku ruchu.

## 3 Argumentacja zastosowania w projekcie

Wybór architektury CoreXY w projekcie CSAimBot nie jest przypadkowy i wynika bezpośrednio z niezwykle rygorystycznych wymagań dotyczących sprzętowego czasu reakcji. Aby robot mógł skutecznie naśladować ruchy gracza, współpracować z analizą obrazu i trafiać w poruszające się cele, jego łączny czas reakcji od momentu detekcji do faktycznego przesunięcia celownika musi wynosić poniżej 200 ms.
Kluczowym argumentem za zastosowaniem CoreXY jest specyfika obciążenia centralnego wózka robota. Należy pamiętać, że wózek w naszym układzie nie porusza się "na pusto". Zostanie do niego podpięty stosunkowo masywny osprzęt: adaptacyjny chwytak (wydrukowany np. z elastycznego materiału TPU), w którym umieszczona będzie fizyczna, bezprzewodowa mysz komputerowa gracza. Dodatkowo, na wózku musi znaleźć się mechanizm "klikacza"– układ szybkich aktywatorów elektromechanicznych (solenoidów lub serwomechanizmów) odpowiedzialnych za fizyczne, mechaniczne wciskanie lewego przycisku myszy (LPM).
Cały ten zestaw (chwytak, mysz, klikacze) stanowi znaczne obciążenie użytkowe (payload). Zastosowanie klasycznej bramy kartezjańskiej z dodatkowym, ruchomym silnikiem krokowym NEMA 23 zamontowanym na wózku, stworzyłoby gigantyczną inercję układu. Próba gwałtownego przyspieszenia tak ciężkiej masy (wymagana np. podczas agresywnej kompensacji odrzutu broni – recoil control) niechybnie prowadziłaby do gubienia kroków przez silniki, wyginania prowadnic i wpadania całej konstrukcji w silne rezonanse i drgania. Unieruchomienie ciężkich silników krokowych na ramie głównej w architekturze CoreXY eliminuje ten problem, pozwalając napędom na wykorzystanie pełnego momentu obrotowego wyłącznie do przemieszczania docelowego osprzętu myszy, gwarantując najwyższą precyzję i dynamikę.

## 4 Zasada działania i kinematyka

Mechanika działania układu CoreXY jest znacznie bardziej złożona niż w prostych układach ortogonalnych. Ruch wózka w płaszczyźnie poziomej nigdy nie jest efektem pracy pojedynczego silnika, lecz zawsze wynika ze wspólnej, zsynchronizowanej pracy obu stacjonarnych napędów krokowych (oznaczonych w modelu jako silnik A i silnik B).

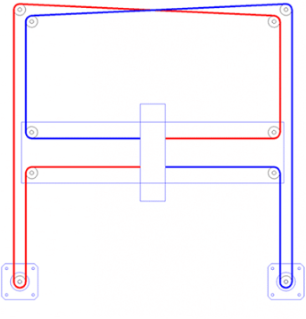
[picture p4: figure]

Rysunek 2: Schemat prowadzenia pasów napędowych (niebieski i czerwony) w układzie CoreXY. Pasy krzyżują się, co zapewnia kompensację sił skręcających wózek.

Zasada sterowania wektorowego opiera się na ciągłym sumowaniu i odejmowaniu obrotów wałów:

- Równoczesny obrót obu silników (A i B) z tą samą prędkością w tym samym kierunku skutkuje czystym ruchem wózka wzdłuż osi X.
- Równoczesny obrót silników (A i B) z tą samą prędkością, ale w kierunkach przeciwnych, wywołuje czysty ruch wzdłuż osi Y.
- Praca wyłącznie jednego z silników (podczas gdy drugi jest mechanicznie zablokowany w spoczynku) wymusza ruch wózka pod kątem 45 stopni po przekątnej płaszczyzny.

Matematyczny model kinematyki prostej, opisujący wektor przemieszczenia wózka (∆X, ∆Y ) w zależności od drogi kątowej pokonanej przez silniki (∆A, ∆B), wyraża się następującym układem równań:

∆X =

1
2
(∆A + ∆B) | (1)

∆Y =

1
2
(∆A − ∆B) | (2)

## 5 Wykaz komponentów układu, ich parametry i zastosowania

Realizacja założonych parametrów kinematycznych wymaga zastosowania wysokiej jakości elementów konstrukcyjnych. Tabela 1 przedstawia rygorystyczny wykaz części wyselekcjonowanych do budowy platformy sprzętowej naszego robota w formie pełnej kratki.

Nazwa Części | Ilość | Parametry | Zastosowanie
Silniki NEMA 23 | 2 szt. | Dwustronny wał 8 mm, moment 2,2 Nm | Główny, stacjonarny napęd układu. Odpowiada za generowanie ruchu pasów i szybkie akceleracje.
Enkodery | 2 szt. | Przystosowane do montażu | Zamknięta pętla sprzężenia zwrotnego. Śledzą rzeczywistą pozycję silników minimalizując błędy.
Zębatki napędowe | 2 szt. | Na wał silnika 8 mm | Bezpośrednio przekazują moment obrotowy z wału silnika NEMA 23 na główny pas zębaty.
Rolki zębate | 6 szt. | Odpowiednie do pasa | Gwarantują precyzyjne prowadzenie pasa w narożnikach ramy zapobiegając jego zsuwaniu.
Rolki gładkie | 2 szt. | Łożyska z kołnierzem | Prowadzą pas od jego płaskiej, bezzębnej strony, utrzymując wymagane napięcie całego układu.
Pas zębaty | 1 szt. | Długość 400–500 cm (z zapasem) | Kluczowy element łączący napędy z wózkiem centralnym, konwertujący ruch obrotowy na liniowy.
Szyny MGN12 | 3 szt. | Prowadnica o długości 40 cm | Przemysłowe prowadnice zapewniające sztywne, bezluzowe prowadzenie osi w płaszczyźnie poziomej.
Profile aluminiowe | 4 szt. | Długość 40 cm | Podstawa konstrukcyjna (rama robota) w kształcie kwadratu, dająca sztywność dla całego układu.
Narożniki | 4 szt. | Wersja do profili 20 | Metalowe złącza krzyżowe podtrzymujące kąty proste ramy (90 stopni) bez luzów strukturalnych.

Tabela 1: Szczegółowy wykaz części układu CoreXY z ich parametrami i przeznaczeniem.

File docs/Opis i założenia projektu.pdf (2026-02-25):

# CSAimBot [CSBot]

## ZSD1

### 1. Krótki opis projektu

Celem projektu jest stworzenie fizycznego AimBota do gry CSGO. Program czytałby ekran z grą, oznaczałby przeciwników oraz zwracał wartość, o którą musiałaby poruszyć się mysz. Do ruchu myszką stworzony zostanie robot typu kartezjańskiego z odpowiednim uchwytem. Robot byłby w stanie zaadaptować się do różnych myszek i wartości DPI. Robot będzie w stanie strzelać i kompensować odrzut broni zapewniając większą dokładność. Klawiszami WASD kierowałby gracz, więc robot musiałby z nim współpracować.

### 2. Zakres funkcjonalny

- Czytanie ekranu
- Oznaczanie przeciwników
- Obliczanie drogi robota
- Ruch myszką za pomocą robota kartezjańskiego
- Strzał za pomocą przycisku
- Rozglądanie się w przypadku braku wykrycia przeciwników
- Współpraca z graczem

### 3. Budowa systemu

- Robot ruszający myszką
Robot typu kartezjańskiego z silnikami krokowymi i enkoderami lub serwomechanizmami dla osi XY i śrubą kulową/trapezową dla osi Z wraz z odpowiednim uchwytem zdolnym do trzymania wielu rodzajów myszek. Robot korygowałby sterowanie w przypadku braku osiągnięcia celownika na przeciwniku oraz kompensował odrzut broni.
- System przechwytujący ekran
Przechwytywanie ekranu odbywać się będzie za pomocą odpowiednich bibliotek w Pythonie/C++ oraz przekazywania przechwyconych klatek do algorytmu wykrywającego przeciwników.
- System wykrywający przeciwników
System bazujący na YOLO będzie wykrywał i oznaczał przeciwników na obrazie i zwracał wartości pozwalające na sterowanie silnikami w robocie w celu namierzenia i eliminacji przeciwnika.

### 4. Etapy wykonania i założenia projektu

Fizyczna budowa robota typu kartezjańskiego Zadania:
- utworzenie modelu robota
- dobór silników i systemu sterującego
- regulator minimalizujący błędy sterowania
- model adaptacyjnego chwytaka (wydrukowany 3d np. z TPU)

Detekcja przeciwnika w grze
Zadania:
- screen capturing
- wykrywanie pozycji przeciwnika na ekranie
- priorytetyzacja zadania największej ilości obrażeń przez wybór odpowiedniej części ciała przeciwnika widzianej na ekranie (najczęściej głowa)
- obliczenie wektora pomiędzy celownikiem, a wyznaczonym punktem

Komunikacja i obsługa robota
Zadania:
- kalibracja ustawień robota odpowiednio do ustawień DPI na danej myszce
- utworzenie połączenia między komputerem, a mikrokontrolerem
- pobieranie informacji o pozycji “najlepszego punktu” przeciwnika do robota
- przesunięcie myszki odpowiednio do informacji
- ewentualna autokorekcja w razie nietrafionego strzału
- kompensacja odrzutu broni

Symulacja robota
Zadania:
- Komunikacja Windows ->ROS na dockerze
- Symulacja robota w Gazebo
- Komunikacja ROS->(Windows)->Robot

### 5. Zastosowane technologie i rozwiązania (Stack technologiczny)

Sprzęt - robot:
- mikrokontrolery
- diody led
- silniki krokowe np. NEMA 17
- sterowniki silników
- śruba kulowa/trapezowa

- zasilacz
- wydrukowany chwytak
- wydrukowane ramię robota
- przetwornice step-down
- serwo do obsługi chwytaka

Sprzęt - komputer:
- komputer z kartą graficzną
- monitor
- myszka
- klawiatura
- launcher do gier Steam oraz gra CS:GO

Oprogramowanie:
- język Python / C / C++ i odpowiednie biblioteki
- YOLO
- PyCharm, Arduino IDE, VSC
- komunikacja szeregowa np. SPI, UART, Wi-Fi, USB
- Repozytorium na GitHubie
- algorytmy kinematyki odwrotnej

### 6. Zespół projektowy

- Tomasz Nazar 197613
- Filip Pietrzak 198275
- Patryk Polechoński 197861
- Hubert Czarnecki 197794
- Karol Puczyński 197676
- Piotr Rokita 197802
- Łukasz Mroczek 198146
- Antoni Sulkowski 197564
- Andrzej Placek 198177
- Łukasz Orluk 197641

### 7. Szczegółowe założenia:

Założenia hardware'owe:

- Projekt będzie działać w temperaturze pokojowej w zamkniętym pomieszczeniu na poziomej płaskiej powierzchni umożliwiającej poprawne zamontowanie robota (np. biurko) i umożliwiającej poprawne użycie klawiatury.
- Robot będzie rozmiarów umożliwiających swobodne sterowanie myszką i wygodnie sterowanie klawiaturą przez użytkownika na jednym stanowisku.
- Mysz, będzie się poruszać na materiałowej podkładce do myszy.
- Komputer i robot, będą pobierały zasilanie z sieci 230V. Dalsze etapy zasilania (np. zasilacz komputerowy), realizowane w zależności od zastosowanego sprzętu.
- Wszystkie komponenty muszą być sprawne, aby projekt działał poprawnie.
- Pozycja silników krokowych będzie odczytywana z enkoderów podłączonych w odpowiedni sposób do silników.
- Mysz użyta do projektu powinna być bezprzewodowa lub powinna mieć kabel o długości zapewniającej swobodną pracę robota.
- Sterowanie robotem będzie odbywać się WYŁĄCZNIE za pomocą myszki i/lub klawiatury oraz dedykowanych przycisków przy robocie
- Mysz musi posiadać przynajmniej 2 przyciski - lewy i prawy przycisk, reszta przycisków będzie ignorowana.
- Mysz musi korzystać z laserowego lub optycznego sensora. Nie może być to mysz kulkowa. Mysz nie może mieć znacznie wystających niestandardowych elementów.
- Przy zmianie myszki/wartości DPI na inną wykonywana będzie półautomatyczna procedura kalibracji. Robot będzie sprawdzał o ile musi się poruszyć, żeby przejść między punktami referencyjnymi na specjalnej mapie.
- Klawiatura będzie obsługiwana przez jednego użytkownika, steruje poruszaniem się klawiszami WSAD
- Projekt nie będzie obsługiwać komend głosowych ani wizji maszynowej.
- Chwytak będzie zamykany serwomechanizmem
- Mysz będzie trzymana siłą tarcia

- Mysz pod chwytakiem robota umieszcza użytkownik w miejscu do tego przeznaczonym (centrum podkładki).
- Nastawy robota będą mogły być zmienione w przypadku poluzowania się części lub wykrycia innych nieprawidłowości.
- Gracz ma do dyspozycji przycisk zatrzymania robota.
- Komunikacja PC-Mikrokontroler poprzez UART (USB) z prędkością 115200 baud
- Przyciski myszy będą naciskane solenoidami lub szybkimi serwomechanizmami.
- Mysz musi mieć klawisze (lewy i prawy) równoległe do powierzchni na której stoi robot. Nie obsługiwane będą myszy typu Logitech MX Vertical itp.
- Akceleracja wskaźnika myszy jest wyłączona.

### Założenia software'owe:

- Program komputerowy będzie działać na systemie Windows 11 Pro build >=25H2 lub równoważnym systemie Windows. Program nie będzie działać na Linuxie ani na MacOS.
- Program będzie działać na komputerze PC o odpowiedniej mocy obliczeniowej (Karta graficzna wspierająca CUDA (min. RTX 3060)) z monitorem - nie na laptopie. Na laptopie może nie zostać spełniony warunek czasu reakcji.
- Program będzie wykrywać modele przeciwników w grze. (Będzie odróżniał modele CT od T)
- Program będzie współpracować z CS:GO w wersji umożliwiającej dodanie botów lub graczy do gry.
- Program będzie komunikował się z robotem za pomocą połączenia przewodowego.
- Program będzie przystosowany do działania lokalnie na komputerze na którym zostanie zainstalowany.
- Ewentualny interfejs użytkownika będzie zrealizowany w języku angielskim.
- Program będzie wykrywał czy użytkownik trzyma pistolet czy karabin za pomocą klasycznej wizji maszynowej (template matching z openCV).
- Jeśli gracz trzyma pistolet lub karabin snajperski to kompensacja odrzutu będzie wyłączona. W przeciwnym wypadku program będzie korygował odrzut konkretnych broni (AK47/M4A1).
- Podczas celowania z karabinu snajperskiego wykrywani zostaną tylko wrogowie znajdujący się w polu widzenia lunety. Włączeniem / Wyłączeniem przybliżenia steruje użytkownik z klawiatury.
- Robot będzie strzelał pojedynczymi strzałami lub seriami w zależności od ustawienia gracza. Odrzut będzie kompensowany jedynie przy strzelaniu seriami.
- Program będzie działał z grą ustawioną na minimum 30 FPS.

- Robot będzie miał 90% celności w cele statyczne.
- Robot będzie miał 60% celności w cele poruszające się.

### Założenia związane z grą:

- Program będzie działał tylko podczas rozpoczętej rundy.
- Program będzie działał na konkretnej mapie (DUST2)
- Program będzie działał z włączoną opcją natychmiastowego usuwania ciał po zabójstwie w grze lokalnej
- W przypadku wykrycia kilku celów, program wybiera cel najbliżej aktualnej pozycji celownika
- Czas reakcji przy eDPI dobranym tak, aby robot nie musiał podnosić myszy będzie wynosił maksymalnie tyle ile czas reakcji dobrego gracza (<200ms) Czasem reakcji nazywamy czas po którym robot zaczyna kierować mysz w stronę przeciwnika od jego pojawienia się na ekranie.

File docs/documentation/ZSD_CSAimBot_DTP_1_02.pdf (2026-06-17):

CSA | Dokumentacja techniczna projektu | Projekt grupowy, WETI PG
PG_WETI_DTP_wer._1.02 | 1 / 12 | Data 17.06.2026 21:19:41

### Dokumentacja projektu grupowego na przedmiot ZSD

# Dokumentacja techniczna projektu

Wydział Elektroniki, Telekomunikacji i Informatyki

Politechnika Gdańska

Nazwa i akronim projektu: CSAimBot, CSBot | Zleceniodawca: dr hab. inż. Michał Czubenko
Numer zlecenia: - | Kierownik projektu: Nazar Tomasz | Opiekun projektu: mgr. inż. Jan Glinko
Nazwa dokumentu/akronim: Dokumentacja techniczna projektu – DTP | Nr wersji: 1.02
Odpowiedzialny za dokument: Pietrzak Filip Nazar Tomasz Puczyński Karol Antoni Sulkowski | Data pierwszego sporządzenia: 7.04.2026

Data ostatniej aktualizacji: 17.06.2026

Studia I stopnia, inżynierskie
Semestr realizacji Projektu grupowego: 2

Historia zmian
Wersja | Opis modyfikacji | Rozdział / strona | Autor modyfikacji | Data
1.00 | Wstępna wersja | całość | Pietrzak Filip | 7.04.2026
1.01 | Wstępne opisanie aplikacji | 2.3 | Puczyński Karol | 19.05.2026
1.02 | Aktualizacja po projekcie | całość | Nazar Tomasz, Sulkowski Antoni | 17.06.2026

PG_WETI_DTP_wer._1.02 | 2 / 12 | Data 17.06.2026 21:19:41

## Spis treści

1 | Wprowadzenie - o dokumencie | 2
1.1 | Cel dokumentu | 2
1.2 | Zakres dokumentu | 2
1.3 | Odbiorcy | 2
1.4 | Terminologia | 2
2 | Założenia i cele projektu | 2
2.1 | Cel projektu | 2
2.2 | Zakres funkcjonalny | 2
3 | Szczegółowe założenia | 2
3.2.1 | Hardware'owe 3
3.2.2 | Software'owe | 3
3.2.3 | Związane z grą 4
Stack Technologiczny | 4
3.2 | Software | 4
3.3 | Hardware | 4
3.4 | Milestone 1: Wstępny model i projekt sprzętowy | 5
3.4.1 | M1 - Software (Wykrywanie w YOLO): 5
3.4.2 | M1 - Hardware (Projekt CAD): 5
3.5 | Milestone 2: Konstrukcja i sterowanie ręczne | 5
3.5.1 | M2 - Software (Aplikacja i integracja wejścia): | 5
3.5.2 | M2 - Hardware (Fizyczny robot): | 5
3.6 | Milestone 3: Pełna integracja (Auto-Aim i kalibracja) | 6
3.6.1 | M3 - Software + Hardware: | 6
4 | Dokumentacja techniczna projektu | 6
4.1 | YOLO oraz Dataset | 6
4.1.1 | Rozmiar datasetu | 6
4.1.2 | Struktura zdjęć 6
4.1.3 | Opis zdjęć - YOLO | 6
4.2 | Robot – fizyczny i symulacja | 6
4.2.1 | Materiały i wykaz elementów | 6
4.2.2 | CoreXY – technologia 7
4.2.3 | Symulacja - technologia7
4.2.4 | Screenshot z symulatora Gazebo | 7
4.2.5 | Modele 3D - technologia | 8
4.3 | Aplikacja i komunikacja z ESP32 | 8
4.3.1 | Architektura Oprogramowania Aplikacji Głównej8
4.3.2 | Struktura klas i modułów | 9
4.3.3 | Architektura interfejsu graficznego oraz inicjalizacja systemu | 10
5 | Napotkane problemy | 11
5.1 | Milestone I | 11
5.2 | Milestone II | 11
5.3 | Milestone III | 11
6 | Perspektywy rozwinięcia projektu | 11
7 | Załączniki | 12

### 1 Wprowadzenie - o dokumencie

### 1.1 Cel dokumentu

{Nie zmieniać}
Celem dokumentu jest udokumentowanie informacji dotyczących produktu, jego cech funkcjonalnych, parametrów technicznych, schematów blokowych, oprogramowania, wyników działania, zdjęć produktu, pomiarów, testów oraz innych elementów wymaganych przez opiekuna i klienta.

PG_WETI_DTP_wer._1.02 | 3 / 12 | Data 17.06.2026 21:19:41

### 1.2 Zakres dokumentu

{Określenie, co wchodzi w zakres dokumentu, a co nie wchodzi, ew. wskazanie na dokumenty powiązane}
Dokument zawiera szczegóły techniczne projektu takie jak: rozmiary, technologie wykonania oraz szczegóły kodu. Dokument nie zawiera szczegółów na temat tego w jakiej kolejności powstały poszczególne części projektu oraz kto jest za nie odpowiedzialny – te opisy są raportowane na wykładach z zajęć z przedmiotu Zintegrowane systemy decyzyjne oraz na repozytorium na githubie

### 1.3 Odbiorcy

{Określenie adresatów dokumentu, może być to typ odbiorcy; tu: zleceniobiorca (Katedra), członkowie zespołu projektowego oraz wymienione z nazwiska osoby, do których dokument ma dotrzeć}
Odbiorcami projektu są dr hab. inż. Michał Czubenko oraz mgr inż. Jan Glinko.

### 1.4 Terminologia

{Wyjaśnienie używanych w dokumencie pojęć i skrótów, oznaczenia używane wewnątrz dokumentu np. oznaczenia wymagań}
Kierownik – kierownik zespołu - Tomasz Nazar
Zastępca kierownika – Filip Pietrzak
Dokument – Niniejszy dokument DTP
Zdjęcia z datasetu - screenshoty z gry Counter Strike: Global Offensive
CS:GO – oryginalna wersja gry Counter Strike: Global Offensive
eDPI - wartość uzyskana po przemnożeniu sensivity – ustawionej czułości w CS:GO – z DPI – ustawionej na komputerze czułości w myszce.

### 2 Założenia i cele projektu

### 2.1 Cel projektu

Celem projektu było stworzenie wpełni funkcjonalnego robota kartezjańskiego zdolnego do samodzielnego celowania w grze CS:GO. Robot miał za zadanie samemu chwycić myszkę i namierzyć wroga na podstawie koordynatów wysyłanych przez system wizyjny.

### 2.2 Zakres funkcjonalny

- Czytanie ekranu
- Oznaczanie przeciwników
- Obliczanie drogi robota
- Ruch myszką za pomocą robota kartezjańskiego
- Strzał za pomocą przycisku
- Rozglądanie się w przypadku braku wykrycia przeciwników
- Współpraca z graczem
- Symulacja robota przez ROS i Gazebo

### 3 Szczegółowe założenia

### 3.1.1 Hardware'owe

- Projekt będzie działać w temperaturze pokojowej w zamkniętym pomieszczeniu na jednolitej poziomej płaskiej powierzchni umożliwiającej poprawne zamontowanie robota (np. biurko) i umożliwiającej poprawne użycie klawiatury.
- Robot będzie rozmiarów umożliwiających swobodne sterowanie myszką i wygodnie sterowanie klawiaturą przez użytkownika na jednym stanowisku.
- Mysz, będzie się poruszać na materiałowej podkładce do myszy.
- Komputer i robot, będą pobierały zasilanie z sieci 230V. Dalsze etapy zasilania (np. zasilacz komputerowy), realizowane w zależności od zastosowanego sprzętu.
- Wszystkie komponenty muszą być sprawne, aby projekt działał poprawnie.
- Pozycja silników krokowych będzie odczytywana z enkoderów podłączonych w odpowiedni sposób do silników.
- Mysz użyta do projektu powinna być bezprzewodowa lub powinna mieć kabel o długości zapewniającej swobodną pracę robota.

PG_WETI_DTP_wer._1.02 | 4 / 12 | Data 17.06.2026 21:19:41
- Sterowanie robotem będzie odbywać się WYŁĄCZNIE za pomocą klawiatury i/lub myszki oraz dedykowanych przycisków przy robocie
- Mysz musi posiadać przynajmniej 2 przyciski - lewy i prawy przycisk, reszta przycisków będzie ignorowana.
- Mysz musi korzystać z laserowego lub optycznego sensora. Nie może być to mysz kulkowa. Mysz nie może mieć znacznie wystających niestandardowych elementów.
- Przy zmianie myszki/wartości DPI na inną wykonywana będzie półautomatyczna procedura kalibracji. Robot będzie sprawdzał o ile musi się poruszyć, żeby przejść między punktami referencyjnymi na specjalnej mapie.
- Klawiatura będzie obsługiwana przez jednego użytkownika, steruje poruszaniem się postacią klawiszami WSAD
- Projekt nie będzie obsługiwać komend głosowych ani wizji maszynowej do poleceń.
- Chwytak będzie zamykany serwomechanizmem
- Mysz będzie trzymana siłą tarcia
- Mysz pod chwytakiem robota umieszcza użytkownik w miejscu do tego przeznaczonym (centrum podkładki).
- Nastawy robota będą mogły być zmienione w przypadku poluzowania się części lub wykrycia innych nieprawidłowości.
- Gracz ma do dyspozycji przycisk zatrzymania robota.
- Komunikacja PC-Mikrokontroler poprzez UART (USB) z prędkością 115200 baud
- Przyciski myszy będą naciskane solenoidami lub szybkimi serwomechanizmami.
- Mysz musi mieć klawisze (lewy i prawy) równoległe do powierzchni na której stoi robot. Nie obsługiwane będą myszy typu Logitech MX Vertical itp.
- Akceleracja wskaźnika myszy jest wyłączona.
- Elementy robota oprócz silników, szyn, sterowników, prowadnic, śrub, zębatek, pasów itp. będą wydrukowane 3d

### 3.1.2 Software'owe

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

PG_WETI_DTP_wer._1.02 | 5 / 12 | Data 17.06.2026 21:19:41
- Program będzie działał z grą ustawioną na minimum 60 FPS.
- Okno wykrywania będzie miało rozmiar 1280x736
- Robot będzie miał 100% celności w cele statyczne.
- Robot będzie miał 60% celności w cele poruszające się.
- Trenowanie YOLO - na komputerze
- Rozdzielczość 1080p
- ROS obsługiwany za pomocą Dockera i WSL2 na Windows

### 3.1.3 Związane z grą

- Program będzie działał tylko podczas rozpoczętej rundy.
- Program będzie działał na dowolnej oficjalnej mapie CS:GO
- Program będzie działał z włączoną opcją natychmiastowego usuwania ciał po zabójstwie w grze lokalnej
- W przypadku wykrycia kilku celów, program wybiera cel najbliżej aktualnej pozycji celownika
- Czas reakcji przy eDPI dobranym tak, aby robot nie musiał podnosić myszy będzie wynosił maksymalnie tyle ile czas reakcji dobrego gracza (<200ms) Czasem reakcji nazywamy czas po którym robot zaczyna kierować mysz w stronę przeciwnika od jego pojawienia się na ekranie.
- Viewmodel będzie ustawiony tak aby było go widać w obszarze przechwytywania

### Stack Technologiczny

### 3.2 Software

- PyCharm >=2025.3.2
- Visual Studio Code >=1.108
- Arduino IDE >=2.3.5
- Python >=3.12
- YOLO26
- Docker + ROS image
- GitHub + Git
- CS:GO - oficjalna wersja legacy
- Autodesk Fusion
- Gazebo
- Bambu Studio

### 3.3 Hardware

- Esp32
- 2x silniki NEMA 23
- 3x sterowniki silników krokowych DM556
- Prowadnice
- Szyny
- Śruba kulowa/trapezowa
- Silnik NEMA 17
- Solenoid
- Logic level converter 3.3V -> 5V
- Zasilacz 36V 10A
- Filament TPU
- Filament PLA/PETG
- Kable
- Nvidia RTX 3060

PG_WETI_DTP_wer._1.02 | 6 / 12 | Data 17.06.2026 21:19:41

### 3.4 Milestone 1: Wstępny model i projekt sprzętowy

### 3.4.1 M1 - Software (Wykrywanie w YOLO):

- Cel: Przetwarzanie obrazu i lokalizacja przeciwników na ekranie, komunikacja z mikrokontrolerem.
- Mierzalny wskaźnik: Średnia precyzja, szybkość przetwarzania (FPS) oraz rozmiar datasetu.
- Dataset / Sposób pomiaru: Ewaluacja na zbiorze testowym złożonym ze screenów z gry na różnych mapach z użyciem wbudowanych skryptów YOLO. Prędkość mierzona podczas gry lokalnej.
- Warunek przejścia dalej: Skuteczność YOLO > 80% dla wykrywania modeli CT/T, stałe utrzymanie min. 60 FPS w czasie inferencji na karcie RTX 3060, dataset o rozmiarze min 5000 zdjęć.

### 3.4.2 M1 - Hardware (Projekt CAD):

- Cel: Zaprojektowanie robota kartezjańskiego zdolnego do przemieszczania i podnoszenia myszki oraz przygotowanie kosztorysu
- Mierzalny wskaźnik: Osiągalna przestrzeń robocza oraz teoretyczny luz mechaniczny.
- Sposób pomiaru: Symulacja kinematyki i pomiary w programie typu CAD (np. Autodesk Fusion).
- Warunek przejścia dalej: Projekt pozwala na pełne pokrycie wirtualnej podkładki o wymiarach min. 30x30 cm, podniesienie uchwytu z myszką w osi Z na wysokość gwarantującą brak odczytu sensora oraz zakupienie części.

### 3.5 Milestone 2: Konstrukcja i sterowanie ręczne

### 3.5.1 M2 - Software (Aplikacja i integracja wejścia):

- Cel: Aplikacja PC czytająca klawiaturę i wysyłająca komendy do mikrokontrolera, symulacja w Gazebo, kompensacja odrzutu broni.
- Mierzalny wskaźnik:Opóźnienie przesyłu danych (Latency) na linii PC -> Mikrokontroler. Rozmiar datasetu oraz skuteczność Yolo.
- Sposób pomiaru: Analiza logów z timestampami wysłania paczki danych oraz potwierdzenia jej odbioru przez UART (115200 baud).
- Warunek przejścia dalej: Skuteczność YOLO > 95%, opóźnienie wysłania pakietu poniżej 5 ms i ~0% zgubionych ramek na dystansie 10 tysięcy prób, dataset o rozmiarze min 10000 zdjęć.

### 3.5.2 M2 - Hardware (Fizyczny robot):

- Cel: Budowa fizycznego robota i weryfikacja poprawności sterowania silnikami z poziomu aplikacji.
- Mierzalny wskaźnik: Czas reakcji mechaniki na komendę.
- Sposób pomiaru: Nagranie w zwolnionym tempie od momentu wciśnięcia przycisku klawiatury do rozpoczęcia ruchu silnika krokowego/serwa.
- Warunek przejścia dalej: Wydrukowane elementy 3D, reakcja silników i fizyczne poruszenie myszką. Czas reakcji<200ms.

### 3.6 Milestone 3: Pełna integracja (Auto-Aim i kalibracja)

### 3.6.1 M3 - Software + Hardware:

- Cel: Integracja całego systemu: YOLO podaje koordynaty, algorytm przelicza je na kroki, a robot fizycznie namierza i strzela.
- Mierzalny wskaźnik: Całkowity czas reakcji układu, celność strzału oraz skuteczność wykrywania broni po stronie gracza.
- Sposób pomiaru: Testy na lokalnym serwerze treningowym (np. Aim Botz). Mierzenie poprzez analizę nagrania z rozgrywki.
- Warunki przejścia dalej:

PG_WETI_DTP_wer._1.02 | 7 / 12 | Data 17.06.2026 21:19:41
- Całkowity czas reakcji układu (Wykrycie -> Ruch) wynosi < 200 ms.
- Dokładność namierzania stojącego celu 100%.
- Półautomatyczna procedura kalibracji eDPI/myszki działa poprawnie.
- System poprawnie włącza/wyłącza kompensację odrzutu na podstawie trzymanej broni (AK47/M4A1 vs Pistolet/Snajperka).

### 4 Dokumentacja techniczna projektu

{O zakresie dokumentacji decyduje opiekun, tu należy zacząć opis rozwiązania technicznego wg zaleceń opiekuna, w układzie redakcyjnym najlepiej oddającym charakter projektu – kolejne rozdziały, podrozdziały, punkty}

### 4.1 YOLO oraz Dataset

### 4.1.1 Rozmiar datasetu

Zdjęc do datasetu jest 10461.

### 4.1.2 Struktura zdjęć

Zdjęcia wykonywane są przy pomocy skryptu pythonowego w wielkości 1280x736 [px] dla Full HD oraz 1728x992 [px] dla 2K (wielokrotności 32 px) oraz skalowane do 1280x736px.

### 4.1.3 Opis zdjęć - YOLO

Opis zdjęć wykonywany jest w Roboflow, na dzień pierwszej wersji dokumentu (7.04.2026) zdjęć opisanych jest ponad 6 tysięcy.

### 4.2 Robot – fizyczny i symulacja

### 4.2.1 Materiały i wykaz elementów

1. Mechanika
- Szyna liniowa MGN12 z wózkiem (40 cm) – 2 szt.
- Szyna liniowa MGN12 z wózkiem (50 cm) – 1 szt.
- Profil aluminiowy T-slot 2020 (40 cm) – 4 szt.
- Narożniki aluminiowe (wersja 20) – 10 szt.
- Pas zębaty GT2 (5 m, 10 mm szerokości) – 1 szt.
- Rolki zębate GT2 – 6 szt.
- Rolki gładkie GT2 – 2 szt.
- Zębatki napędowe na wał silnika 8 mm – 2 szt.
- Śruba trapezowa osi Z (skok 2 mm, 10 cm) – 1 szt.
- Sprzęgło 8x5 mm – 1 szt.
- Pręt stalowy 3 mm (długość 330 mm) – 2 szt.
- Filament (TPU, 1,75mm, 1 kg) – 1 szt.
2. Silniki i sterowniki
- Silnik krokowy Nema 23 (dwustronny wał 8 mm) – 2 szt.
- Silnik krokowy Nema 17 "Pancake" – 1 szt.
- Sterownik cyfrowy DM556 – 3 szt.
- Enkoder obrotowy E6B2-CWZ6C (600 P/R) – 2 szt.
3. Chwytak i klikanie
- Serwo MG996R (180 stopni) – 1 szt.
- Zębatka serwa 25T (Moduł 0.5) – 1 szt.
- Listwa zębata (Moduł 0.5, 5x5x300mm) – 1 szt.
- Solenoidy 12V – 2 szt.
4. Elektronika i sterowanie
- Mikrokontroler ESP32 – 1 szt.
- Konwerter poziomów logicznych TXS0108E (8-kanałowy) – 1 szt.
- Przetwornica LM2596 ADJ (Regulowana) – 2 szt
5. Zasilanie

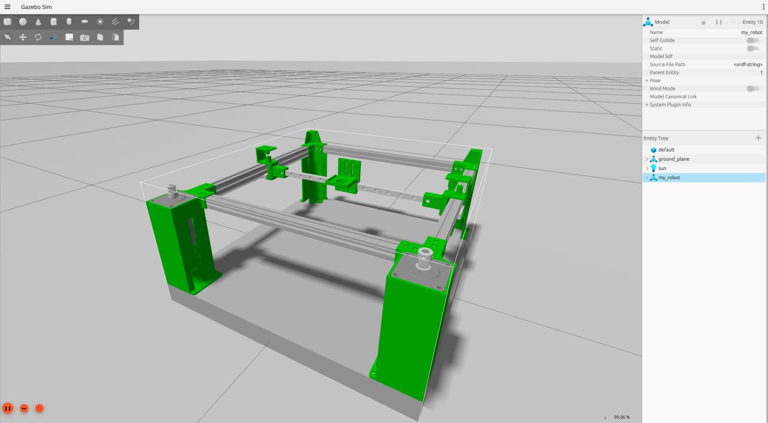
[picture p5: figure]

PG_WETI_DTP_wer._1.02 | 8 / 12 | Data 17.06.2026 21:19:41
- Zasilacz (36V, 10A, 360W) – 1 szt.
6. Dodatkowe części drukowane
- Chwytak Fin Ray – 2 szt.
- Podstawy do silnika – 2 szt.
- Elementy wydrukowane (na Githubie)

### 4.2.2 CoreXY – technologia

Wybór kinematyki CoreXY w projekcie CSAimBot jest podyktowany wymogiem uzyskania czasu reakcji poniżej 200 ms. Architektura ta opiera się na stacjonarnym montażu silników napędowych na ramie głównej, podczas gdy ruch wózka realizowany jest za pośrednictwem układu pasów zębatych. Rozwiązanie to drastycznie zmniejsza masę ruchomą i inercję całego systemu.

### 4.2.3 Symulacja - technologia

Symulacja została zrealizowana przy użyciu środowiska ROS. Wirtualny model robota oraz fizyka otoczenia symulowane są w programie Gazebo, z kolei narzędzie RViz odpowiada za graficzną reprezentację danych z systemu sterowania.

### 4.2.4 Screenshot z symulatora Gazebo

### 4.2.5 Modele 3D - technologia

Modele 3D, projektowane w oprogramowaniu Autodesk Fusion, służą zarówno do stworzenia wirtualnej symulacji w środowisku Gazebo, jak i do fizycznej budowy robota kartezjańskiego z wykorzystaniem technologii druku 3D.

### 4.3 Aplikacja i komunikacja z ESP32

### 4.3.1 Architektura Oprogramowania Aplikacji Głównej

Aplikacja sterująca robotem CSAimBot została zaprojektowana w oparciu o architekturę wieloprocesową. Rozdzielenie tych zadań na osobne procesy pozwala na ich równoległe wykonywanie i zapobiega blokowaniu interfejsu użytkownika podczas obciążających operacji wejścia/wyjścia lub obliczeń na GPU.

System składa się z jednego procesu głównego oraz dedykowanych procesów pomocniczych:
- Proces Główny (app.py): Punkt wejścia aplikacji. Inicjuje wszystkie procesy potomne, zarządza kanałami komunikacyjnymi. Proces ten centralizuje przepływ informacji – odbiera dane takie jak status z ESP32, czy potrzebny dystans do pokonania przez robota do trafienia w przeciwnika od procesów potomnych i dystrybuuje do nich odpowiednie komendy (np. zmianę priorytetu celu).

PG_WETI_DTP_wer._1.02 | 9 / 12 | Data 17.06.2026 21:19:41
- Vision Worker (aimbot.py): Niezależny proces odpowiedzialny za cały potok wizyjny. Realizuje asynchroniczne przechwytywanie klatek obrazu z ekranu, transfer danych bezpośrednio do pamięci VRAM oraz inferencję modelu do detekcji przeciwników. Wynikiem działania tego procesu jest ciągły strumień obliczonych przesunięć w osiach X i Y względem środka ekranu do wroga, przesyłany z określoną częstotliwością do procesu głównego.
- Comms Worker (comms.py): Proces odpowiadający za dwukierunkową komunikację sprzętową. Utrzymuje i monitoruje połączenie szeregowe z ESP32, asynchronicznie przesyłając ramki sterujące (zawierające m.in. wyliczone przesunięcia, stany przycisków myszy oraz prędkość) i odbierając statusy urządzenia.
- Simulation Worker (sim_worker.py): Proces odseparowujący logikę sterowania środowiska symulacyjnego od warstwy fizycznej robota. Zarządza komunikacją ze środowiskiem ROS2/Gazebo oraz symulowaną kinematyką układu.
- Mouse Blocker Worker (mouse_blocker_worker.py): Proces odpowiedzialny za programowe filtrowanie wejść z myszy fizycznej. Jego zadaniem jest zablokowanie dodatkowych przycisków i funkcji (takich jak przycisk środkowy, rolka), przepuszczając wyłącznie ruch oraz kliknięcia lewym i prawym przyciskiem myszy. Mechanizm ten uniemożliwia rejestrowanie przypadkowych akcji podczas fizycznego zaciskania chwytaka robota na obudowie myszy, co mogłoby zdestabilizować działanie programu. Proces ten aktywowany jest równolegle z procesem Vision Worker.

### 4.3.2 Struktura klas i modułów

W celu zapewnienia pełnej modułowości oprogramowania oraz separacji zadań, logika aplikacyjna podsystemu sterowania, komunikacji i detekcji została podzielona na niezależne moduły. Każdy z modułów odpowiada za realizację ściśle zdefiniowanego zadania i wykonuje się w odrębnym procesie. Poniżej przedstawiono szczegółowy opis struktury klas oraz metod wchodzących w skład struktury projektu.

Moduł wizyjny i inferencji (aimbot.py) Moduł ten stanowi rdzeń potoku przetwarzania obrazu. Odpowiada za realizację inferencje modelu YOLO w czasie rzeczywistym oraz wyznaczanie błędu między pozycją aktualną a zadaną.
- Klasa AimBot: Główna klasa zarządzająca potokiem wizyjnym. Odpowiada za konfigurację regionu przechwytywania, przygotowanie modelu YOLO oraz statyczną alokację zmiennych w pamięci GPU.
- prepare_camera(): Definiuje statyczny obszar przechwytywania ekranu (FOV o rozdzielczości 1280x736 pikseli) dopasowany do środka rozdzielczości monitora głównego.
- prepare_model(model_path): Odpowiada za inicjalizację instancji sieci YOLO oraz wykonanie fazy rozgrzewkowej przy użyciu pustego tensora w pamięci CUDA w celu eliminacji opóźnień przy pierwszej klatce.
- allocate_variables(): Dokonuje alokacji obiektów i tensorów w pamięci VRAM karty graficznej.
- capture_and_preprocess_frame(): Pobiera surowy tensor z providera kamery, normalizuje wartości pikseli do zakresu [0.0, 1.0] i przepisuje dane bezpośrednio do tensora wejściowego modelu.
- calculate_best_target_position(boxes_data_tensor): Realizuje algorytm wyboru celu. Nadaje najwyższy priorytet klasom powiązanym z głową przeciwnika, a w przypadku ich braku przełącza się na klasy korpusu. W obrębie wybranej grupy priorytetowej selekcjonuje obiekt położony najbliżej środka ekranu i wylicza przesunięcie w pikselach.
- recoil_compensation(offset_x, offset_y): Wprowadza wirtualną poprawkę w osi pionowej symulującą przeciwdziałanie odrzutowi broni palnej, bazując na aktualnej broni.
- process_single_frame(): Koordynuje pojedynczy cykl: wywołuje akwizycję obrazu, uruchamia inferencję sieci, aktualizuje stany wewnętrzne oraz opcjonalnie nakłada warstwę diagnostyczną OpenCV (okno debugowania).

PG_WETI_DTP_wer._1.02 | 10 / 12 | Data 17.06.2026 21:19:41
- Funkcja vision_worker(pipe_conn, model_path, target_fps): Funkcja uruchomieniowa procesu Vision Worker. Kontroluje taktowanie pętli przetwarzania, nasłuchuje komend zmiany parametrów z kanału komunikacyjnego (np. zmiana priorytetu celu na TT/CT/ALL) i asynchronicznie przesyła wyliczone przesunięcia do procesu głównego.

Moduł akwizycji obrazu (camera.py) Warstwa abstrakcji sprzętowej izolująca platformę systemową od mechanizmu pobierania klatek obrazu.
- Klasa CameraProvider: Zapewnia kompatybilność wieloplatformową potoku wizyjnego.
- __init__(region): Automatycznie wykrywa system operacyjny hosta. Na platformie Windows inicjalizuje bibliotekę bettercam wykorzystującą interfejs NVIDIA Direct3D Desktop Duplication API. Na platformach Linux uruchamia moduł mss.
- grab_gpu_tensor(): Pobiera aktualny zrzut zdefiniowanego regionu ekranu i natychmiast mapuje go do struktury tensora PyTorch bezpośrednio w pamięci karty graficznej, całkowicie omijając pamięć RAM i narzut procesora.
- release(): Zwalnia zasoby systemowe powiązane z przechwytywaniem obrazu.

Moduł komunikacji szeregowej i wejścia (comms.py) Odpowiada za warstwę transportową danych pomiędzy środowiskiem uruchomieniowym Python a mikrokontrolerem ESP32 oraz za przechwytywanie fizycznych naciśnięć klawiszy.
- Klasa SerialCommsModule: Implementuje asynchroniczną komunikację UART poprzez port USB.
- connect(): Otwiera port szeregowy z prędkością transmisji 115200 bodów i zarządza opóźnieniem wymaganym na restart układu po zestawieniu połączenia.
- check_connection(esp, port): Realizuje procedurę uwierzytelnienia. Wysyła zapytanie sekwencyjne "ESP32-CHECK" i oczekuje przez określony czas na flagę "ESP32-READY".
- send_command(command): Koduje tekstową ramkę sterującą do formatu UTF-8, dodaje znak powrotu karetki (\r) zgodny z protokołem i wymusza opróżnienie bufora wyjściowego.
- get_response(): Odczytuje nadchodzące pakiety zwrotne z ESP32, dekoduje je i usuwa znaki niedrukowalne.
- Klasa KeyboardInputModule: Niskopoziomowy watęk nasłuchujący zdarzeń klawiatury systemowej za pomocą biblioteki pynput.
- on_press(key) / on_release(key): Dodaje lub usuwa z wewnętrznej struktury zbioru zdefiniowane klawisze sterujące, eliminując problem powtórzeń systemowych.
- get_key(): Przetwarza stan wciśniętych klawiszy. W pierwszej kolejności weryfikuje wystąpienie klawisza wyłączenia awaryjnego, a w przypadku jego braku generuje ciąg znaków reprezentujący aktualny wektor manualnego sterowania osiami.
- Funkcja comms_worker(conn): Funkcja zarządzająca procesem Comms Worker. Agreguje dane z potoku IPC interfejsu graficznego, wysyła sformatowane ramki sterujące (zawierające offsety, prędkość, stany przycisków myszy) z zachowaniem bezpiecznego interwału czasowego i przekazuje zwrotne logi diagnostyczne z ESP32 do interfejsu GUI.

Moduł filtrowania przycisków myszy (mouse_blocker_worker.py) Realizuje zadania związane z izolacją fizycznych peryferiów od działań systemu automatycznego sterowania.
- Funkcja mouse_blocker_worker(pipe_conn): W zależności od wykrytej platformy operacyjnej wywołuje dedykowane funkcje blokujące:
- _run_windows_blocker(): Wstrzykuje filtr zdarzeń biblioteki pynput do kolejki komunikatów systemu Windows. Przechwytuje i blokuje kody komunikatów powiązane ze scrollem, przyciskiem środkowym oraz przyciskami bocznymi, zapobiegając ich rejestracji przez system operacyjny.
- _run_linux_blocker(): Przejmuje bezpośrednią kontrolę nad deskryptorem pliku fizycznej myszy w podsystemie evdev za pomocą metody grab(). Tworzy wirtualny interfejs wejściowy UInput, na który przekazuje wyłącznie surowe zdarzenia relatywne ruchu oraz podstawowe stany kliknięć (BTN_LEFT, BTN_RIGHT), całkowicie odcinając pozostałe przerwania sprzętowe.

PG_WETI_DTP_wer._1.02 | 11 / 12 | Data 17.06.2026 21:19:41

### 4.3.3 Architektura interfejsu graficznego oraz inicjalizacja systemu

Zwieńczeniem architektury oprogramowania jest proces główny, który integruje wszystkie procesy pomocnicze i zapewnia interfejs graficzny. Został on zrealizowany przy użyciu biblioteki Dear PyGui.

Punkt wejścia i inicjalizacja (app.py) Skrypt startowy aplikacji, odpowiedzialny za bezpieczne powołanie do życia środowiska wieloprocesowego.
- Wykorzystuje bibliotekę multiprocessing do utworzenia niezależnych kanałów łączności dla każdego z workerów (wizyjnego, komunikacyjnego, symulacyjnego oraz blokady myszy).
- Odpowiada za zarządzanie cyklem życia procesów potomnych – ich poprawne uruchomienie, a w przypadku zamknięcia aplikacji (lub wystąpienia błędu krytycznego) – przesłanie sygnałów terminacji oraz zwolnienie zasobów za pomocą metody join().
- Obsługuje dodatkowe flagi uruchomieniowe (np. --export-only), które pozwalają na wywołanie skryptu w trybie kompilacji przestrzennej modelu YOLO do zoptymalizowanego formatu TensorRT (silnik .engine) przed właściwym startem aplikacji.

Klasa interfejsu użytkownika (gui.py) Zarządza warstwą graficzną oraz dwukierunkową wymianą danych za pośrednictwem dedykowanych potoków komunikacyjnych.
- Zarządzanie stanem i nawigacja: Interfejs opiera się na wielozakładkowym układzie z rozwijanym panelem bocznym. Przełączanie poszczególnych widoków (Strona Główna, Panel Sterowania, Symulacja, Statystyki, Ustawienia) realizowane jest poprzez manipulację właściwością widoczności odpowiednich grup widżetów.
- Responsywność i skalowanie: Aplikacja natywnie obsługuje rozdzielczości 720p oraz 1080p.
- Wielojęzyczność: Interfejs posiada wbudowany słownik, który mapuje etykiety tekstowe i opisy na wybrane warianty językowe (polski/angielski).
- Wizualizacja telemetrii: Aplikacja wykorzystuje wbudowane silniki renderowania wykresów do prezentacji danych w czasie rzeczywistym. Generowane są wykresy historii pozycji robota w osiach X i Y oraz dystansu do wykrytego celu.
- Asynchroniczna pętla zdarzeń: Aby uchronić główną pętlę renderującą Dear PyGui przed zablokowaniem, odbiór komunikatów od procesów pomocniczych został oddelegowany do osobnego wątku. Wątek ten w nieprzerwanej pętli odpytuje potoki za pomocą metody i w przypadku wykrycia nowych pakietów danych (np. statusu połączenia, logów UART z ESP32) aktualizuje odpowiednie zmienne stanu aplikacji oraz powiązane widżety tekstowe.

### 5 Napotkane problemy

### 5.1 Milestone I

- Zatkana dysza drukarki 3D
- Długi czas oczekiwania na zamówione części
- Brak pasujących sprzęgieł do enkoderów
- Wysoka cena komponentów

### 5.2 Milestone II

- Konieczność lekkiego redesignu UI/UX aplikacji w celu wprowadzenia nowych funkcjonalności
- Problemy z konwerterem poziomów logicznych
- Zepsute serwo
- Zrzucenie projektu na podłogę
- Wyginanie się elementów i luzy w konstrukcji chwytaka
- Święta - wyjazd członków zespołu
- Chwilowe zmniejszenie rozmiaru drużyny
- Dodrukowanie części z powodu złych pomiarów
- Przegrzewający się elektromagnes
- Zabrakło kabli

### 5.3 Milestone III

- Problemy z konwerterami, osią Z oraz solenoidami

PG_WETI_DTP_wer._1.02 | 12 / 12 | Data 17.06.2026 21:19:41
- Spalony step-down
- Luźne sprzęgło
- Pęknięty kluczowy element robota oraz konieczność demontażu całej konstrukcji
- Spalony sterownik silnika NEMA23

### 6 Perspektywy rozwinięcia projektu

- Robot mógłby rysować przy zmianie końcówki.
- Robot mógłby grać w szachy przy zmianie końcówki.
- Robot mógłby służyć za niedokładną drukarkę 3D przy zmianie końcówki.
- Robot mógłby współpracowac z systemem autonomicznego poruszania się po mapie CS. Taki system mógłby działać za pomocą AI i chodzić po mapie w losowe miejsca omijając przeszkody.

### 7 Załączniki

Załączniki znajdują się na repozytorium GitHub.

https://github.com/ZSD-CSAimBot/CSAimBot

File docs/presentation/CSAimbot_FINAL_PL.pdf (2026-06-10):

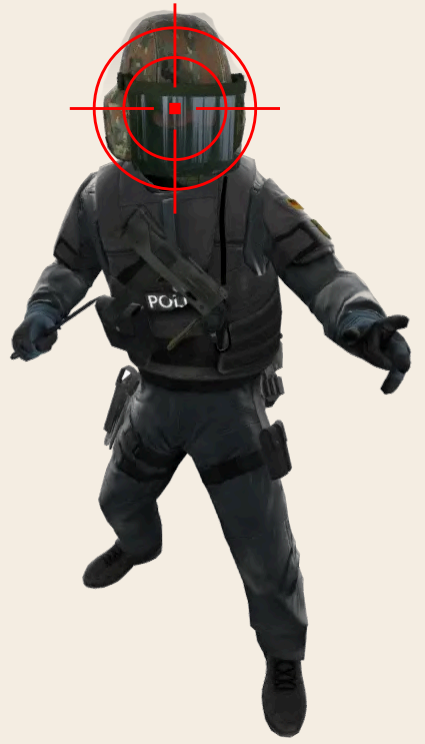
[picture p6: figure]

10 Czerwca 2026

Prezentowane przez
Tomasz Nazar, Filip Pietrzak

# CSAIMBOT

# CELE PROJEKTU M1+M2+M3

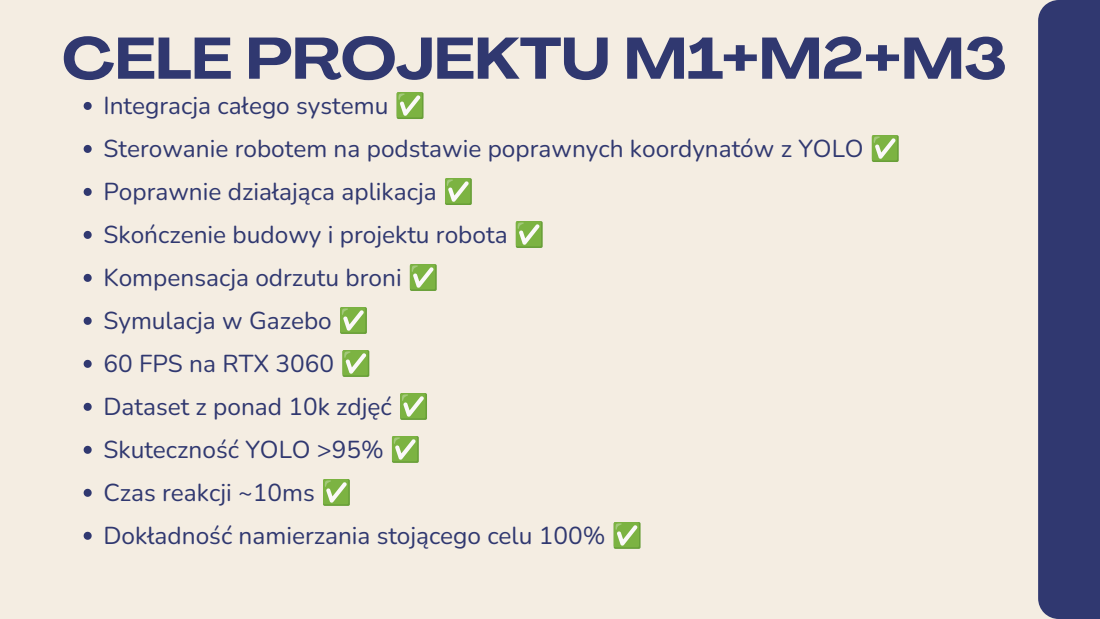
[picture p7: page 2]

Integracja całego systemu ✅
Sterowanie robotem na podstawie poprawnych koordynatów z YOLO ✅
Poprawnie działająca aplikacja ✅
Skończenie budowy i projektu robota ✅
Kompensacja odrzutu broni ✅
Symulacja w Gazebo ✅
60 FPS na RTX 3060 ✅
Dataset z ponad 10k zdjęć ✅
Skuteczność YOLO >95% ✅
Czas reakcji ~10ms ✅
Dokładność namierzania stojącego celu 100% ✅

# OSIĄGNIĘTE REZULTATY

# APLIKACJA

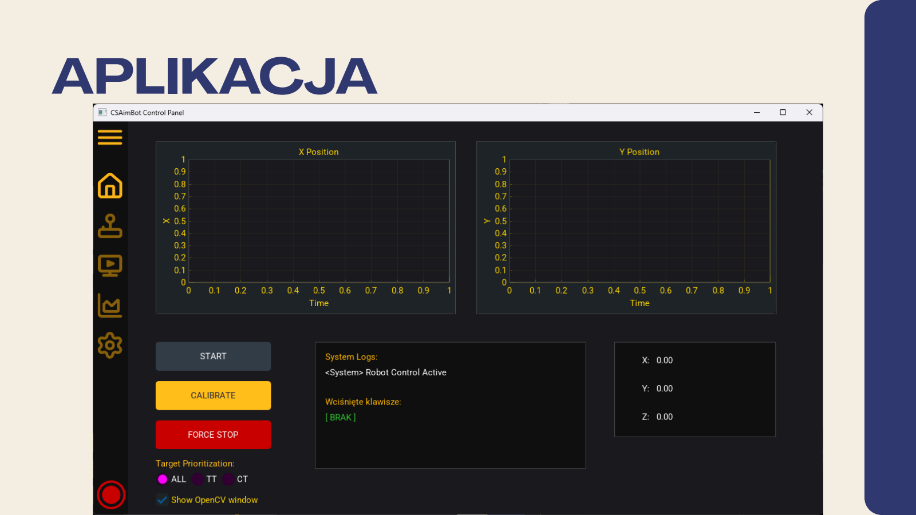
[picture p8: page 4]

# APLIKACJA

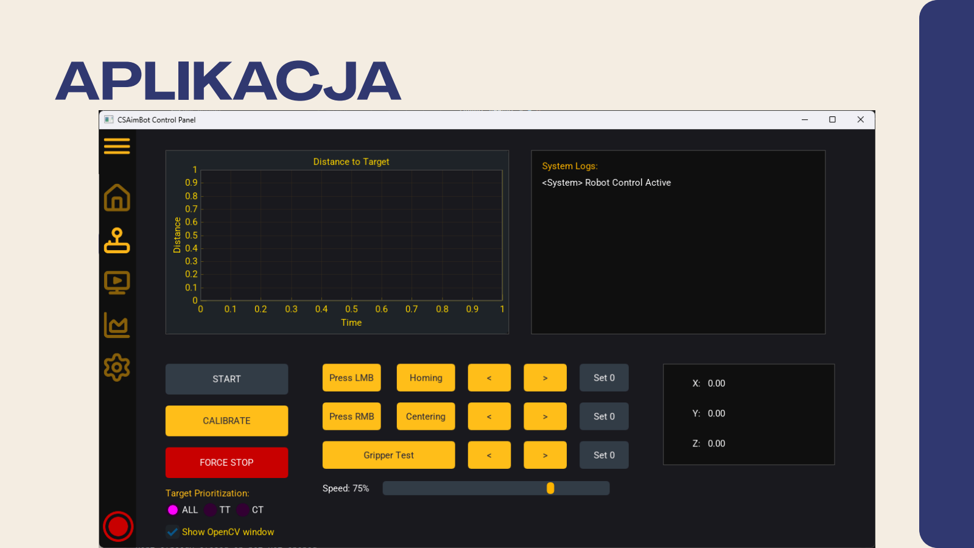
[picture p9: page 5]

# APLIKACJA

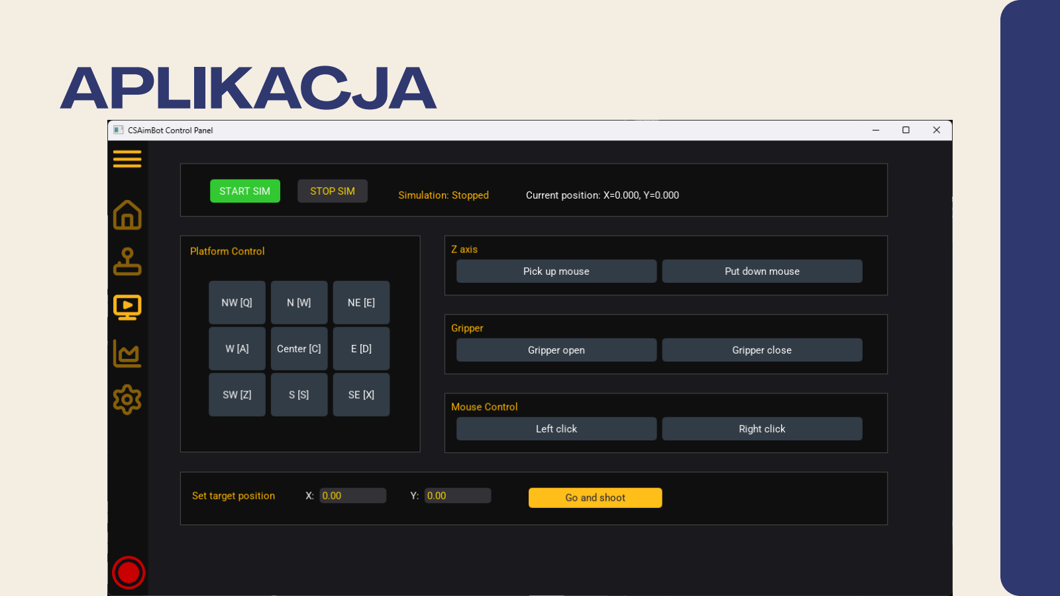
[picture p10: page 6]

# APLIKACJA

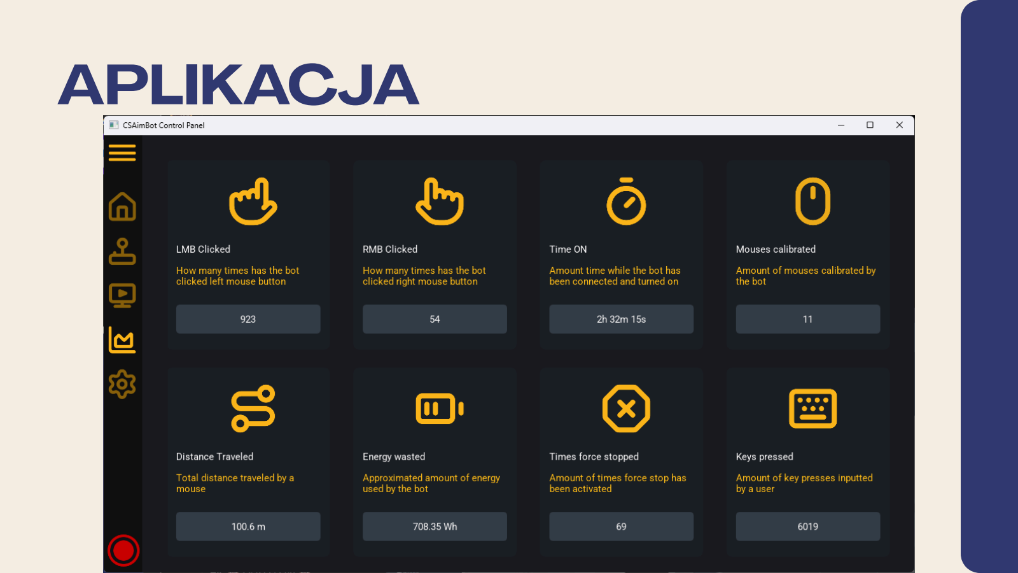
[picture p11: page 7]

# APLIKACJA

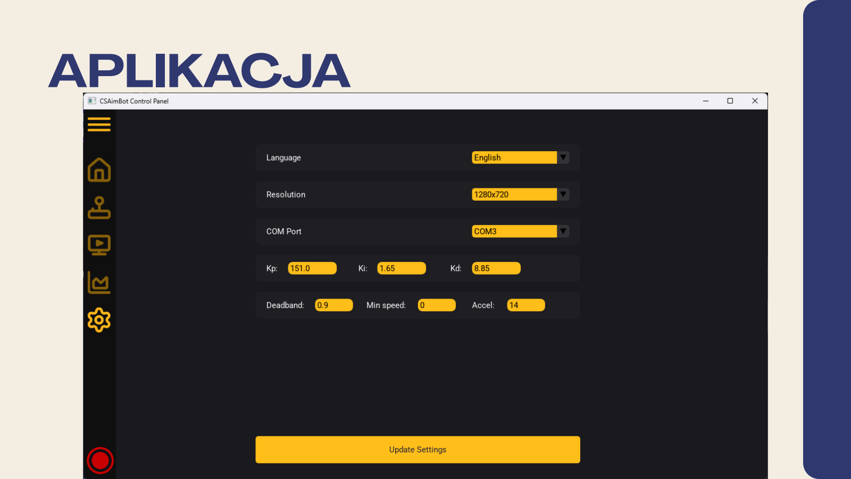
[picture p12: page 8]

# INSTALLERY

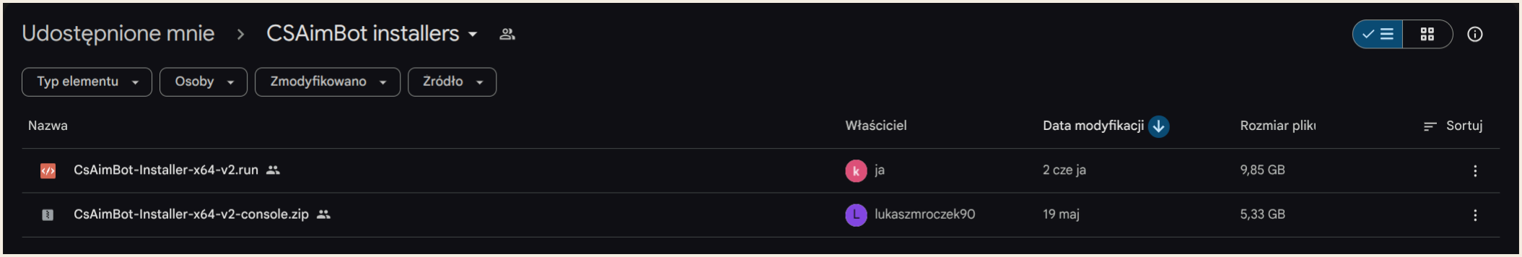
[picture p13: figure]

# INSTALLER WINDOWS

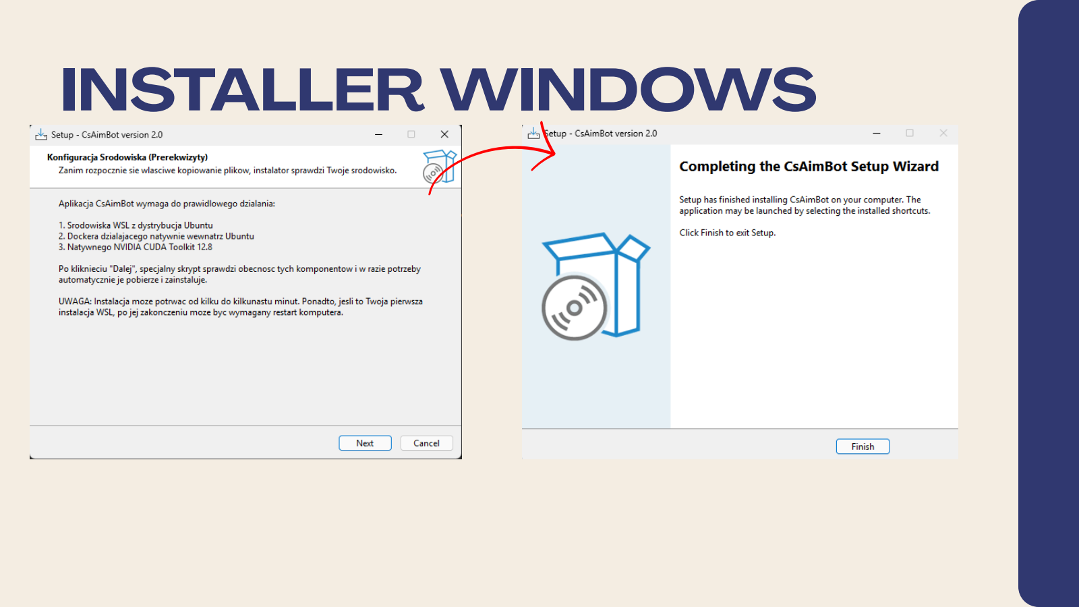
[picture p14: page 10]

# INSTALLER LINUX

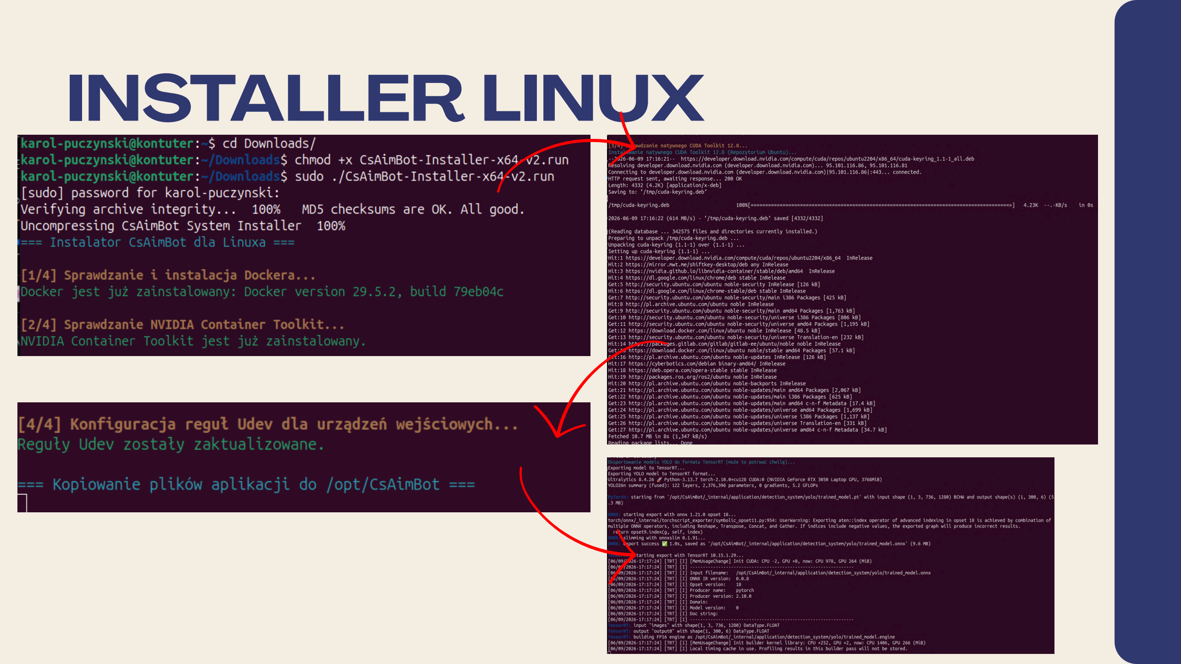
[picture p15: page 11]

# INSTALLER LINUX

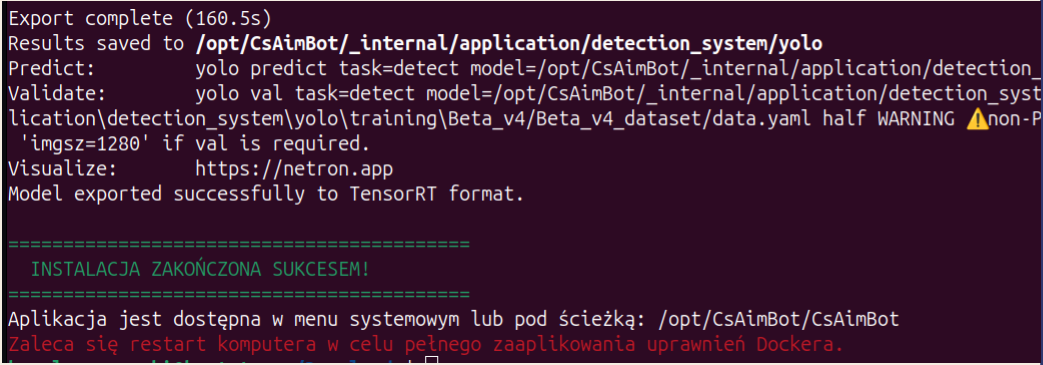
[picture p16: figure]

# HARDWARE

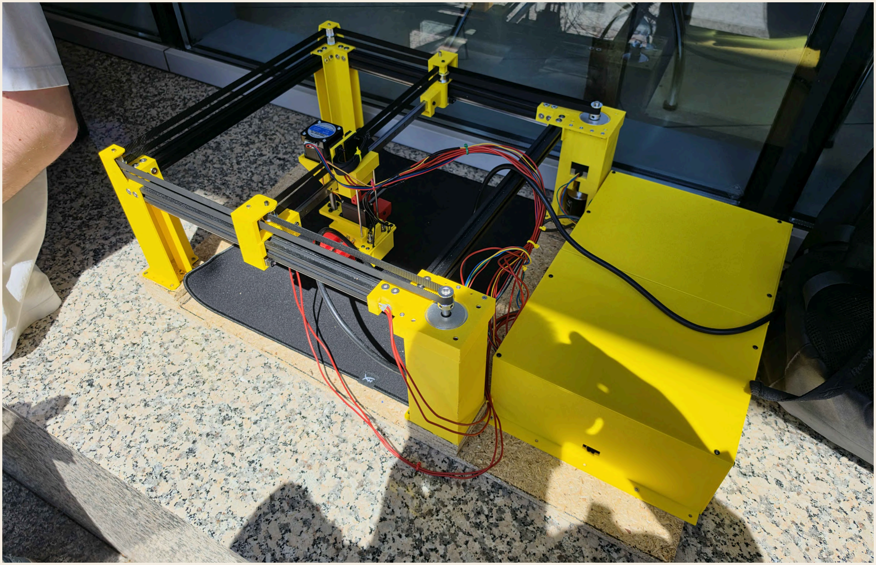
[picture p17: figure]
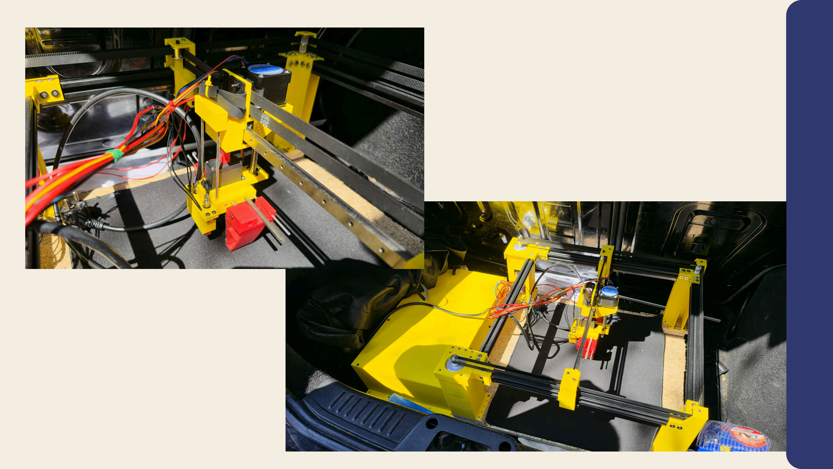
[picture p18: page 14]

# DRUK 3D

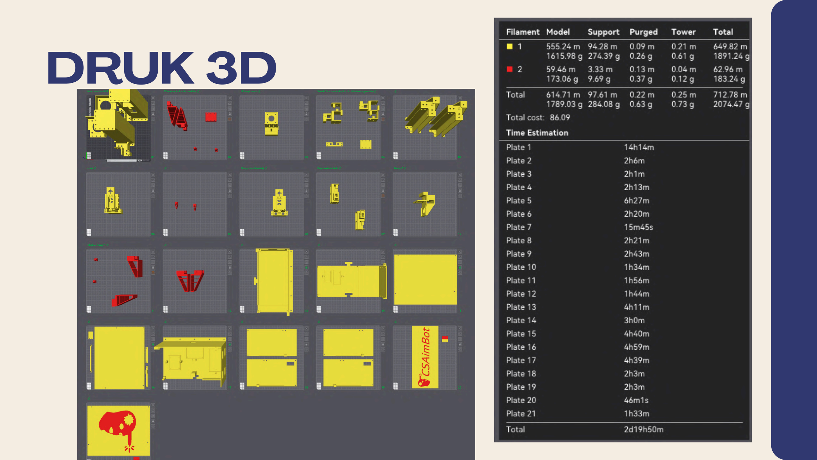
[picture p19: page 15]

# INSTRUKCJA

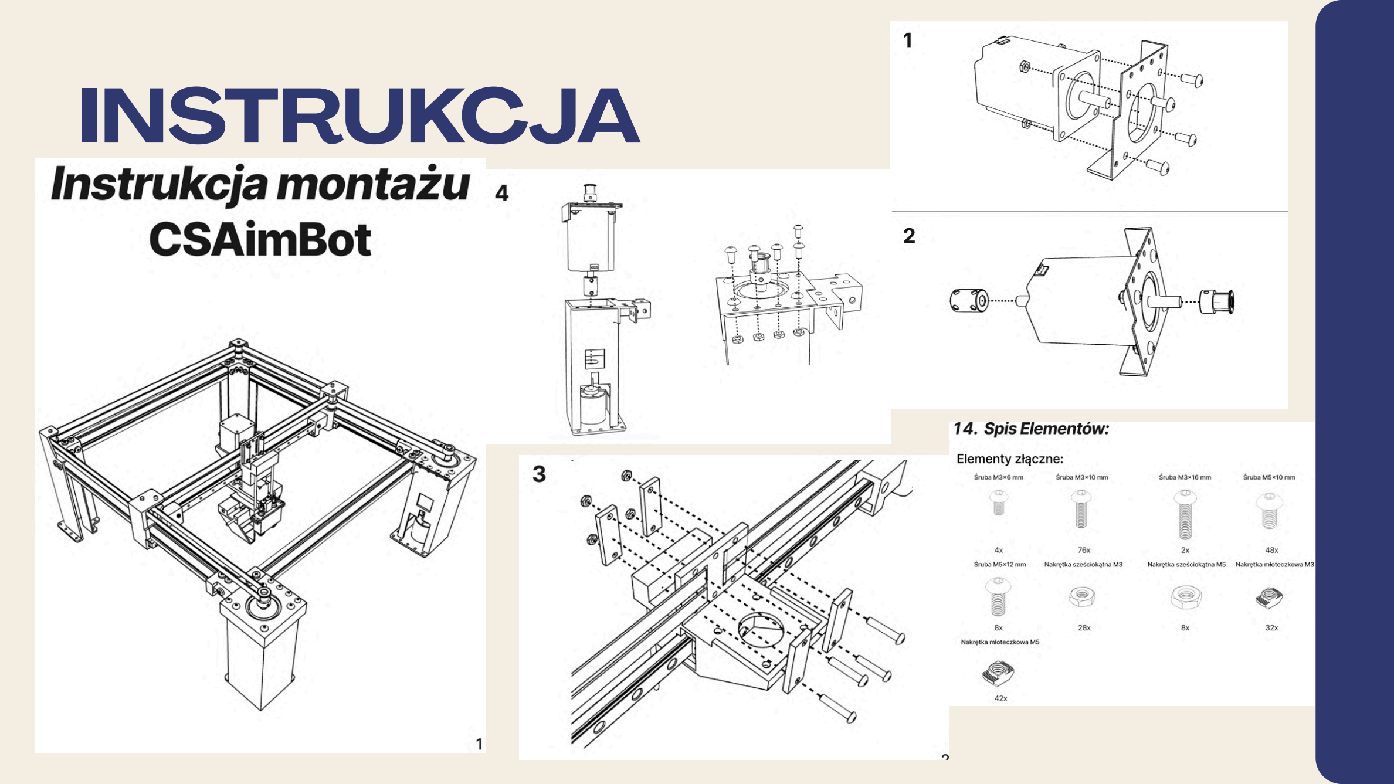
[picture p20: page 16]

# INSTRUKCJA

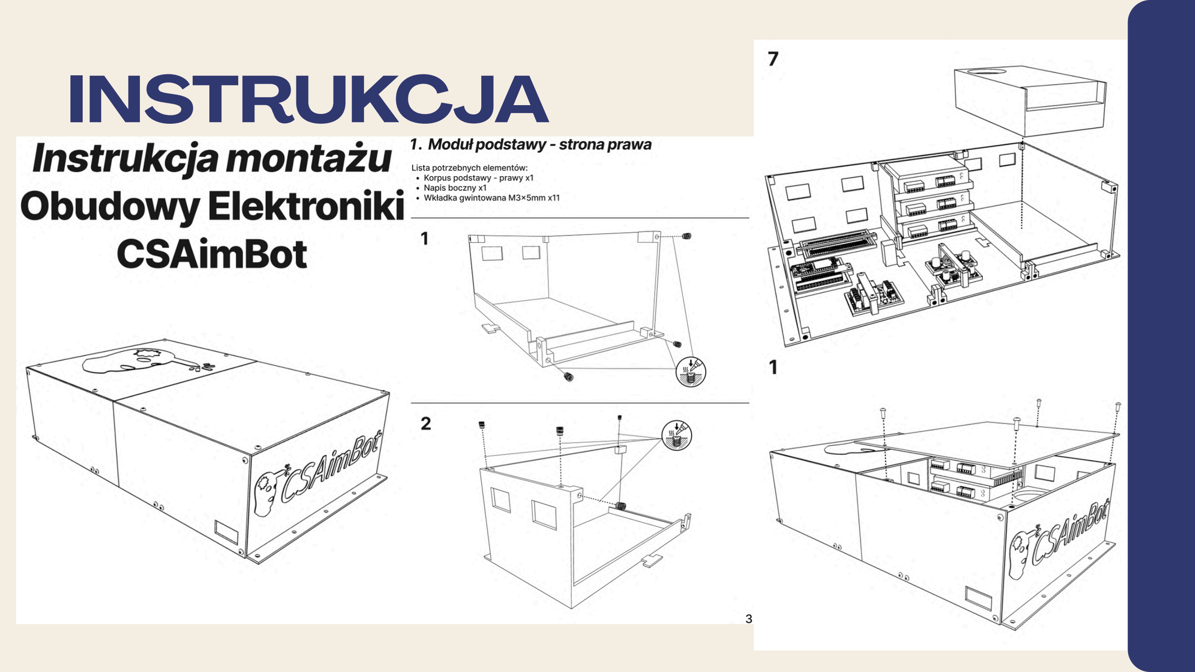
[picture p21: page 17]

# EFEKT KOŃCOWY

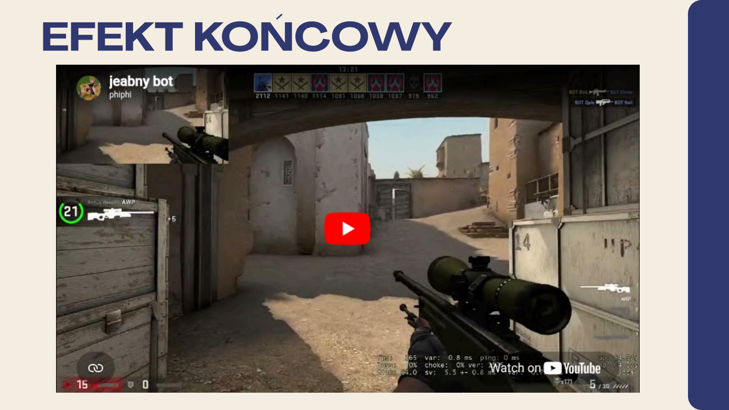
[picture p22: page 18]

# EFEKT KOŃCOWY

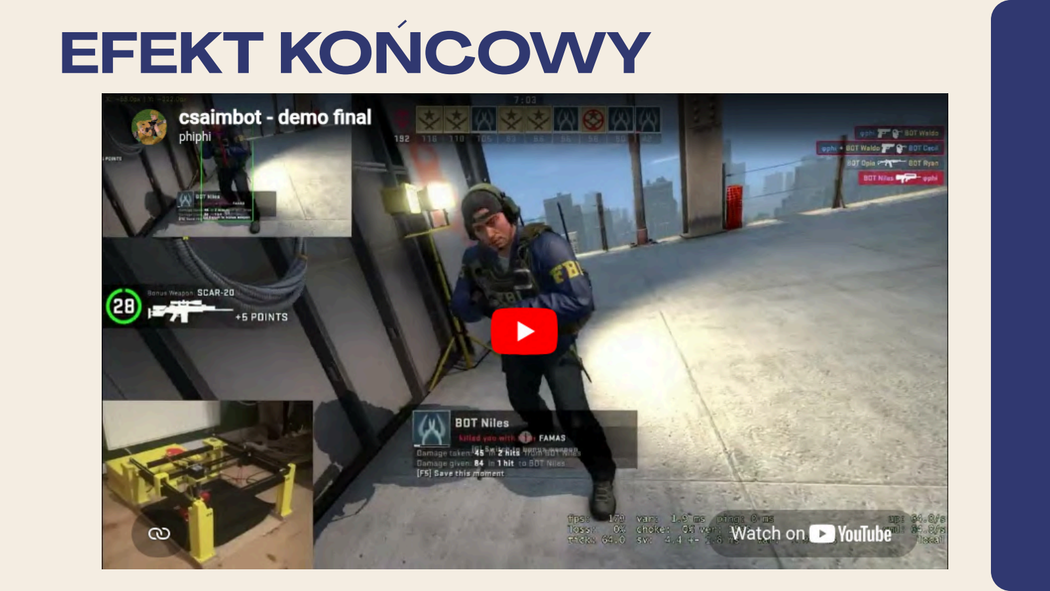
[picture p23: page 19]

# PROBLEMY

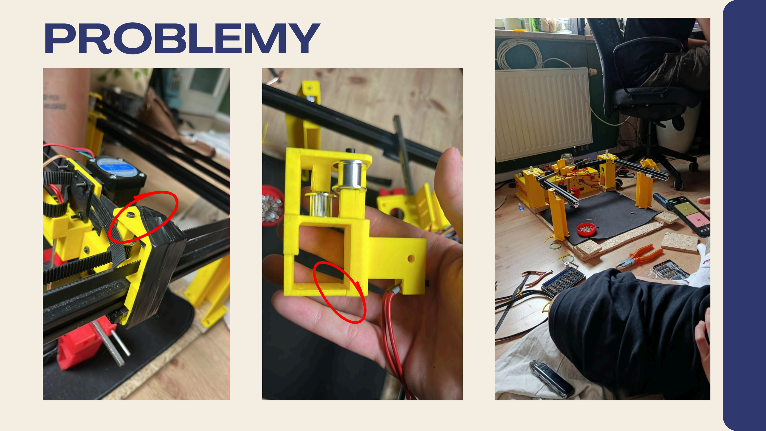
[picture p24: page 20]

# POKAZ NA ŻYWO

# DZIĘKUJEMY

10 Czerwca 2026

Prezentowane przez
Filip Pietrzak, Tomasz Nazar

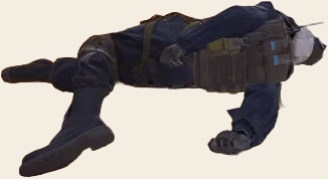
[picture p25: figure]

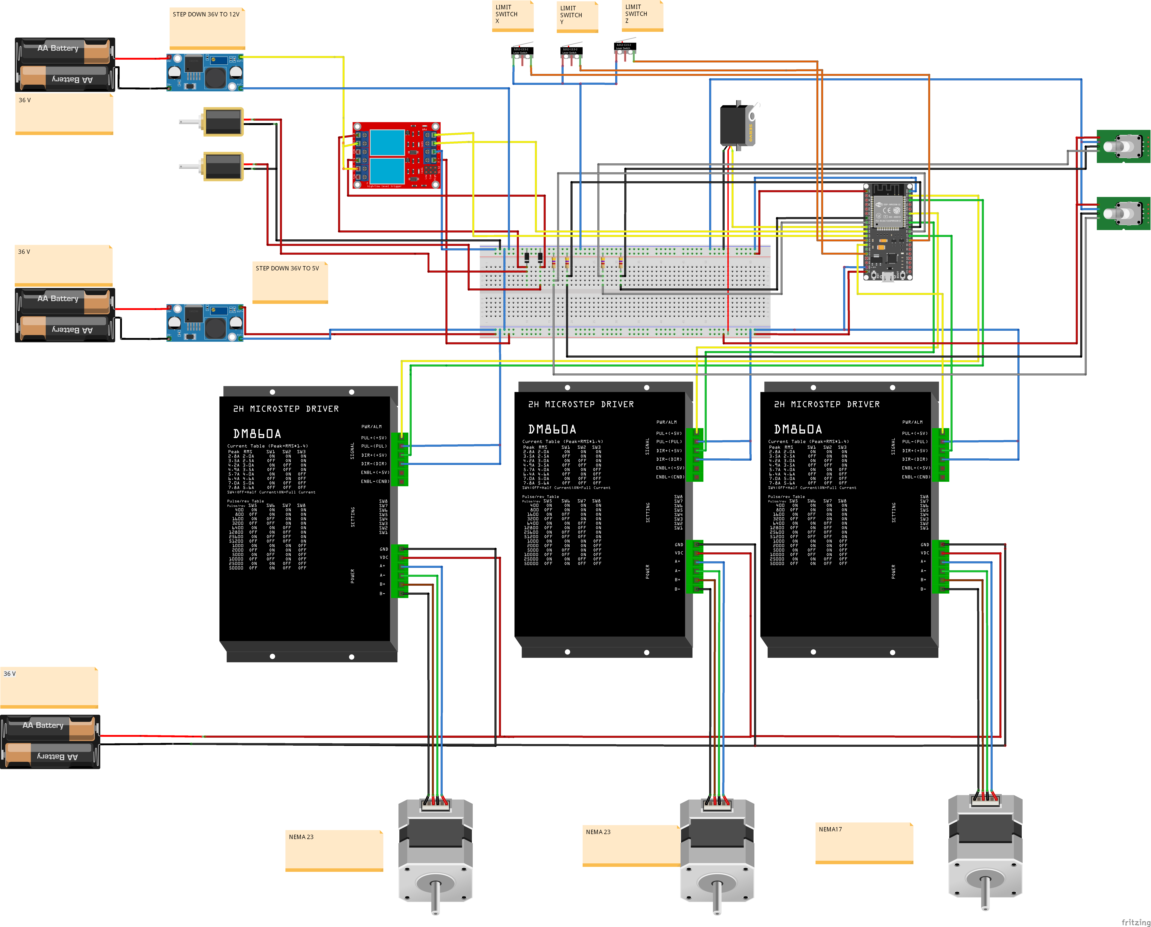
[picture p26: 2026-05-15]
docs/electrical_layout/ELECTRONIC_SCHEME_FINAL_VERSION.png

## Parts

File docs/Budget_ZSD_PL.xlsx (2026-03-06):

Platforma 40x40
Obszar roboczy 30x30
 | Nazwa | Potrzebna ilość elementów | Cena | Link
CoreXY | Nema 23 (corexy) - dwustronny wał po 8 mm średnicy 2,2 Nm | 2 | 62,89 za 1 szt. (z nowym kontem 39.74) | aliexpress (https://pl.aliexpress.com/item/32812732434.html?src=google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)
 | Enkodery | 2 | 29,68 zl za 1szt | aliexpress (https://pl.aliexpress.com/item/1005003450164127.html)
 | Zębatki napędowe (do silników (wał silnika Nema23 8mm)) | 2 | 14,48 za 5szt | temu (https://www.temu.com/pl/5-szt--kompatybilne-ko%C5%82a-pasowe-gt2-do-drukarek-3-8mm-otw%C3%B3r-10mm-szeroko%C5%9B%C4%87-ko%C5%82a-z-kluczem-imbusowym-wytrzyma%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)
 | Rolki zębate | 6 | 14zl za 1szt | poltech24 (https://poltech24.pl/lozyskowana-zebatka-gt2-20t-rolka-zebata-5mm-20-zebow-na-pasek-o-szerokosci-10-mm-p-2316.html)
 | Rolki gładkie (łożyska z kołnierzem) | 2 | 14zl za 1szt | poltech24 (https://poltech24.pl/lozyskowana-rolka-bez-zebow-gt2-20t-5-mm-na-pasek-o-szerokosci-10-mm-p-2401.html)
 | Pas zębaty (minimum 400-500cm by był zapas) | 1 | 36,22 bez przeceny za calosc | aliexpress (https://pl.aliexpress.com/item/32921042288.html)
 | Szyna MGN12 (Prowadnica) 40cm | 3 | 69,99 szt. | temu (https://www.temu.com/pl/solidna-szyna-mgn12-z-otworem-monta%C5%BCowym-precyzyjny-system-ruchu-liniowego-kompatybilny-z-drukarkami-3d-diy-i-maszynami-cnc-sprz%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)
 | prfile (jakos 20cm ale to moze drukniemy) 4szt
 | Profile aluminiowe 4x40cm | 4 | 44,68zl 2szt - 40cm | temu (https://www.temu.com/pl/2-szt-profile-aluminiowe-t-slot-2020-standard-europejski-do-mebli-diy-szafek-stolik%C3%B3w-herbacianych-100-150-200-300-400-500-600-mm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)
 | Narożniki (wersja 20) | 4 | 12,31zl 10szt. | temu (https://www.temu.com/pl/zestaw-10-sztuk-wspornik%C3%B3w-naro%C5%BCnych-z-profilu-aluminiowego-serii-20-30-40-k%C4%85towe-wsporniki-pod-k%C4%85tem-prostym-dla-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)
Oś Z | Śruba na osi Z (skok 2mm) (10cm powinno starczyc) | 1 | 12,34 za szt. | aliexpress (https://pl.aliexpress.com/item/32333490360.html)
 | Silnik do Z | 1 | 21,49 szt. | aliexpress (https://pl.aliexpress.com/item/1005003874936862.html?curPageLogUid=3B29JjdqeypH)
 | Silniki do klikania (5N to troche duzo lepiej znalezc mniej ale ciezko) | 2 | 27,89 za 2szt. | temu (https://www.temu.com/pl/zestaw-2-szt-jf-0530b-liniowy-elektromagnes-push-pull-6v-12v-24v-si%C5%82a-5n-pr%C4%85d-300ma-skok-10mm-konstrukcja-metalowa-do-zastos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)
 | Sprzęgło 8x5 | 1 | 7,6 szt | temu (https://www.temu.com/pl/przek%C5%82adnia-wa%C5%82owa-z-elastycznymi-szcz%C4%99kami-d19-l25-przek%C5%82adnia-silnika-krokowego-cnc-do-encodera-maszyny-grawerne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)
 | Silnik do chwytaka (180 stopni powinno starczyc niby 4,6cm zakres ruchu)(55g troche ciezszy ale pasuje do tej zebatki) | 1 | 15,36 szt | temu (https://www.temu.com/pl/1-2-4-paczka--silniki-seryjne-180-55g-metalowy-z%C4%99baty-moment--cyfrowy-silnik-seryjny-odpowiedni-do---jr-rc-helikoptera-%C5%82odzi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)
 | Zębatka do silnika chwytaka (drogo ale jak ktos znajdzie taniej to smialo) | 1 | 38,89zl 2szt | aliexpress (https://pl.aliexpress.com/item/1005010684512704.html?gad_source=1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)
 | Listwa zębata (0.5 Mod! 5x5x300)(potrzebujemy 2 sztuk ale ta ma 30cm wiec jak sie przetnie to jedna starczy) | 1 | 23,69 1szt | aliexpress (https://pl.aliexpress.com/item/1005009911055935.html)
 | pręt 3mm (330mm dlugosc) | 2 | 16,13 - 5szt | temu (https://www.temu.com/pl/pr%C4%99ty-ze-stali-nierdzewnej-o-%C5%9Brednicach-od-2-mm-do-10-mm-i-d%C5%82ugo%C5%9Bci-125-mm-lub-330-mm-g-601099639708077.html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)
Elektronika / Inne | Filament | 1 | 36,99zl 1kg | allegro (https://allegro.pl/oferta/filament-tpu-professional-lab-1-75mm-1kg-czerwony-18282682861)
 | DM556 (sterowniki XYZ) | 3 | 19,76zl 1szt | aliexpress (https://pl.aliexpress.com/item/32861267422.html)
 | Konwerter | 1 | 5,94 2szt | temu (https://www.temu.com/pl/2-3-5-szt-txs0108e-szybki-konwerter-poziomu-logicznego-full-duplex-8-kana%C5%82owy-spi-8-drogowy-3-3v-5v-iic-8-bitowy-dwukierunkowy-mo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)
 | ESP32 | 1 | 17,11 1szt | aliexpress (https://pl.aliexpress.com/item/1005005953505528.html?curPageLogUid=wr4N73tvb3om)
 | Zasilacz (36v 10a) | 1 | 130zl szt | allegro (https://allegro.pl/oferta/zasilacz-impulsowy-36v-360w-10a-cnc-silnik-krokowy-17440158027)
 | Przetwornica | 2 | 13,21 2szt | aliexpress (https://pl.aliexpress.com/item/1005010451961156.html?curPageLogUid=GzUmQPeTt2Px)

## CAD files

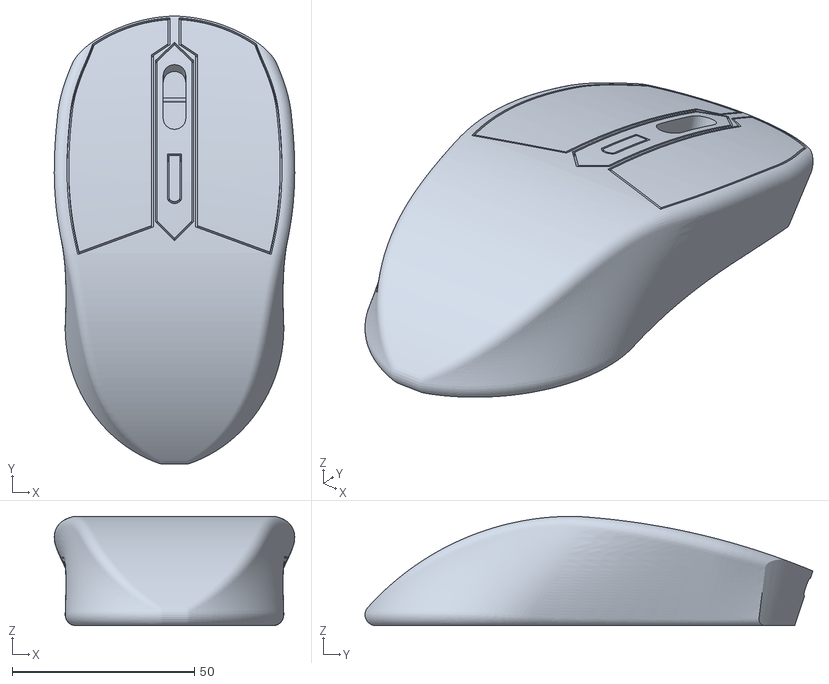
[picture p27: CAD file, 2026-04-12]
application/simulation/src/robot_bringup/meshes/mouse.stl
66.0 x 122.9 x 30.0

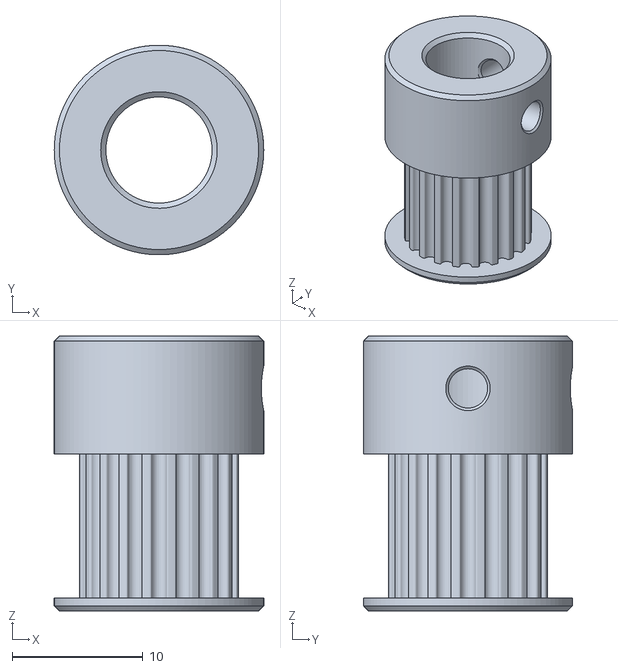
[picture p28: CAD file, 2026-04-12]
application/simulation/src/robot_description/meshes/zebatka_napedowa.stl
16.0 x 16.0 x 21.0

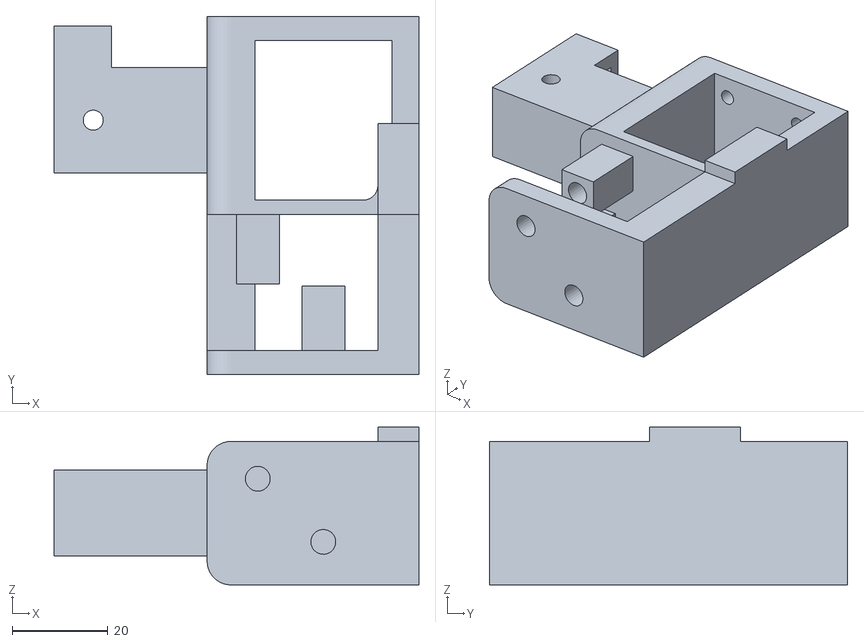
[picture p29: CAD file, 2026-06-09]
docs/3d_models/Mocowanie_Wozek_Lewy.stl
76.3 x 74.9 x 33.0

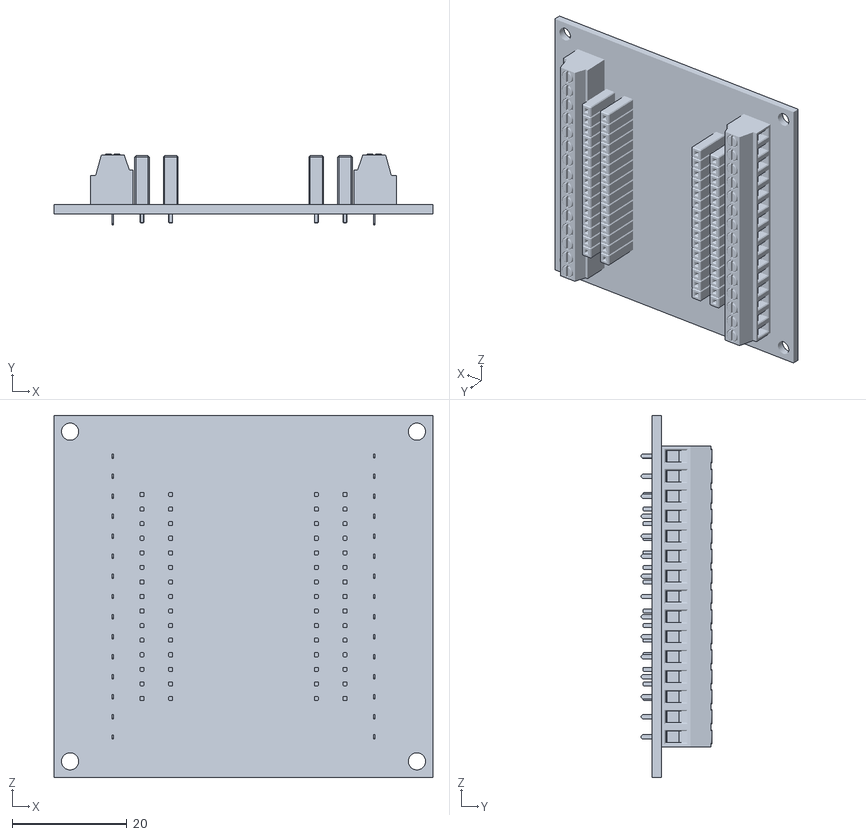
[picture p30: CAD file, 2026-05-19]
docs/3d_models/Pudelko/Electronic_Parts/ESP32_Terminal_Adapter.stl
66.1 x 12.4 x 63.2

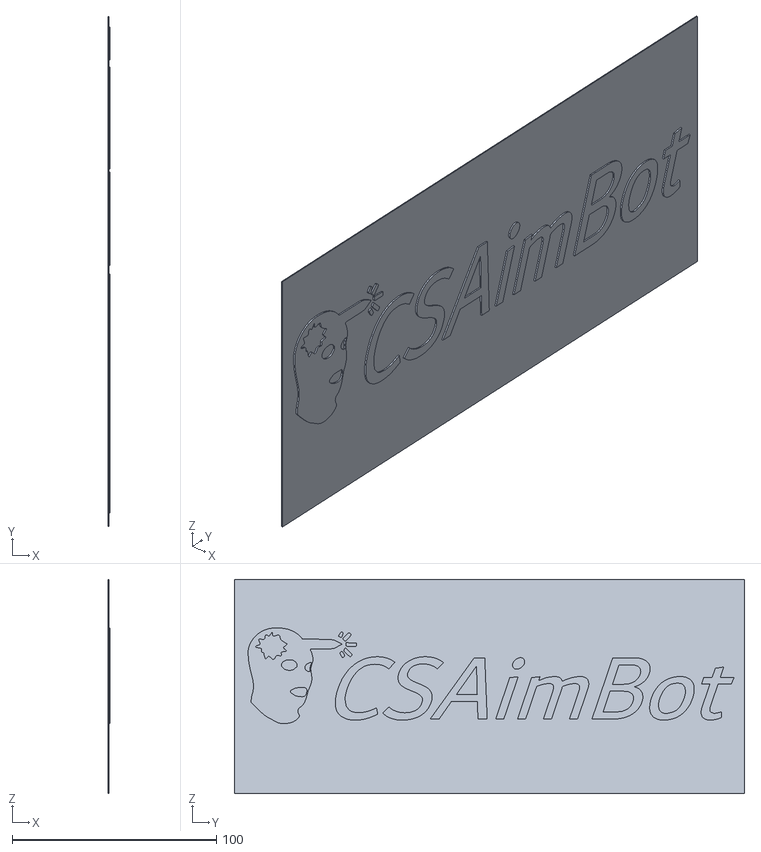
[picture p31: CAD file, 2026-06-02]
docs/3d_models/Pudelko/Pudelko_Napis_Bok.stl
1.00 x 250.0 x 105.0

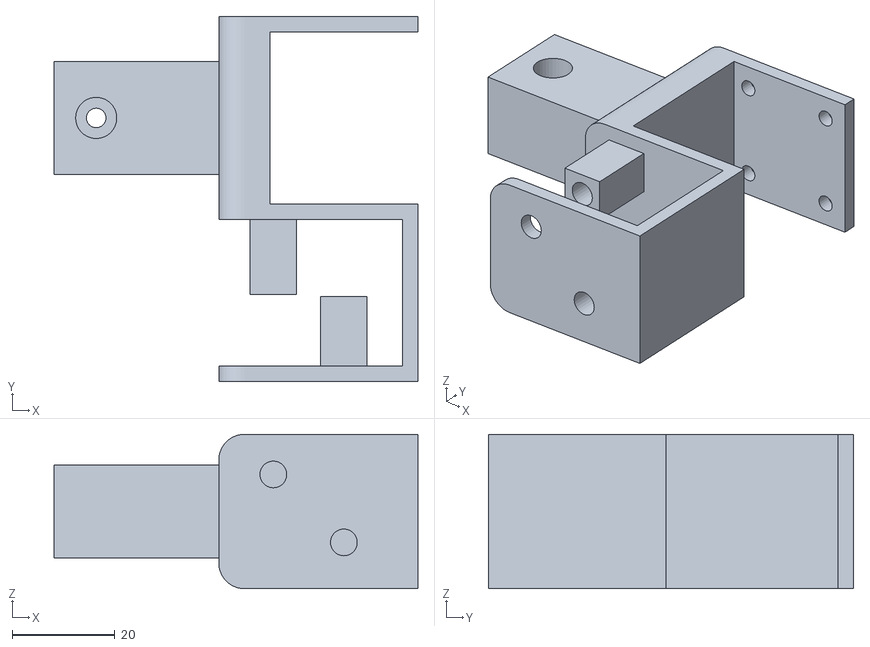
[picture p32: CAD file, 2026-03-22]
docs/projekt/Mocowanie_Wozek_Lewy.stl
70.7 x 70.9 x 30.0

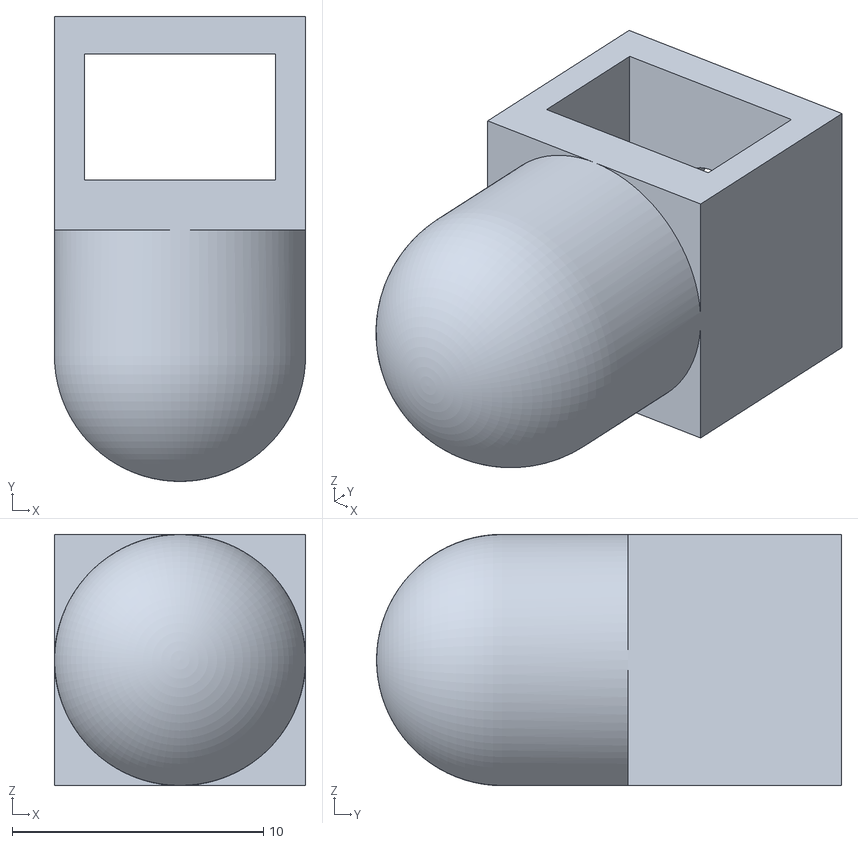
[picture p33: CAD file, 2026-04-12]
application/simulation/src/robot_description/meshes/nakladka_solenoid.stl
10.0 x 18.5 x 10.0

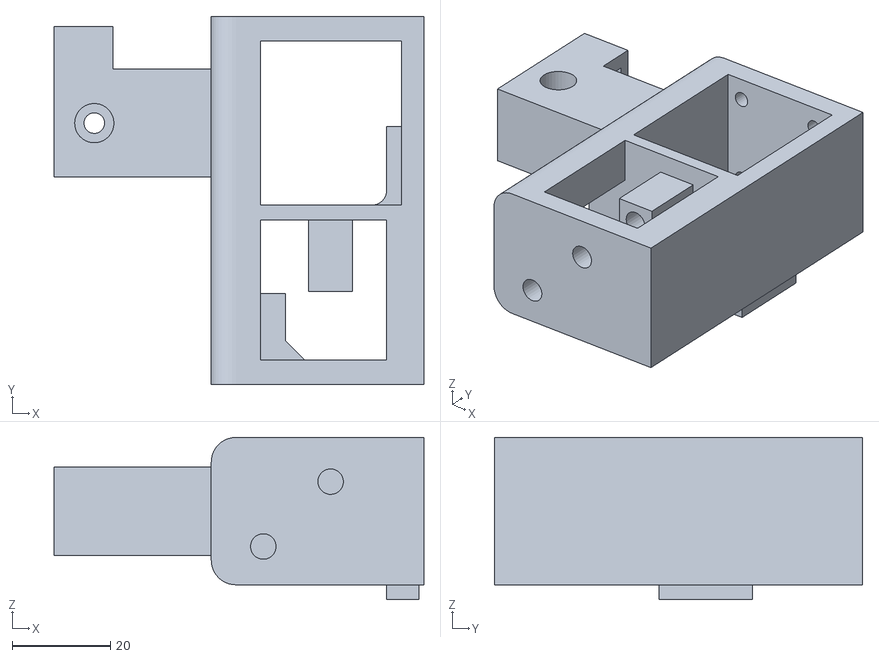
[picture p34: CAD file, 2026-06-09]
docs/3d_models/Mocowanie_Wozek_Prawy.stl
75.3 x 74.9 x 33.0

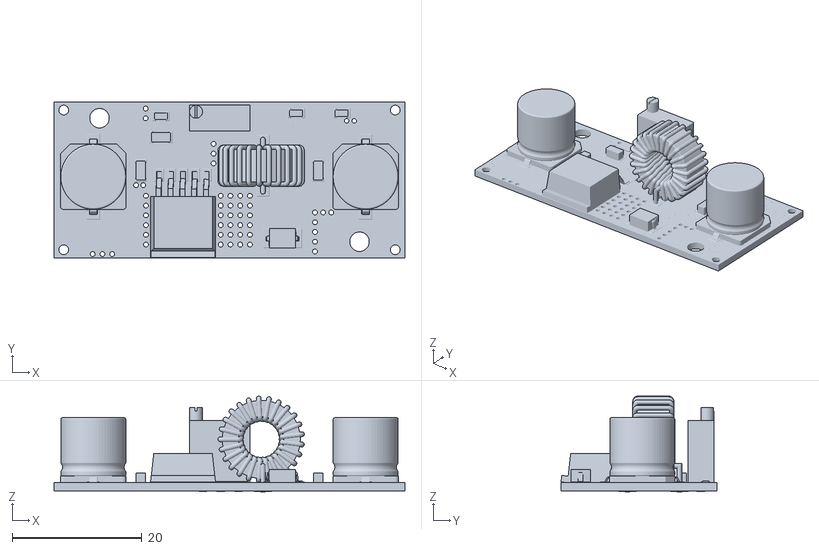
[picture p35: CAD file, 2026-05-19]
docs/3d_models/Pudelko/Electronic_Parts/XL4015.stl
54.0 x 24.0 x 14.8

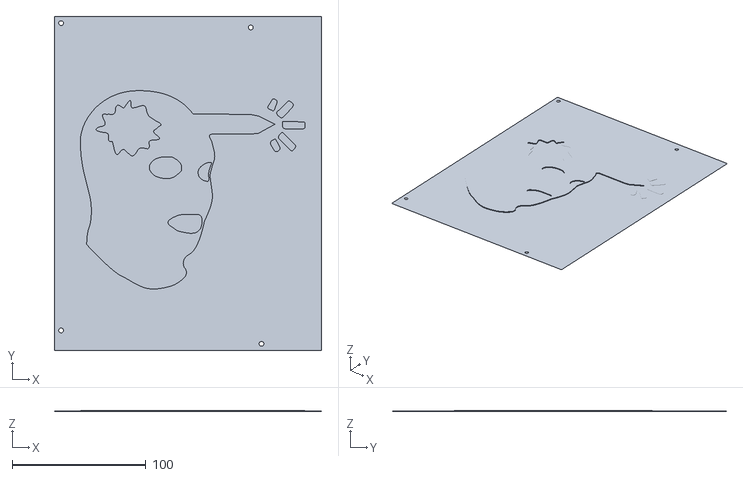
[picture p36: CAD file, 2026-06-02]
docs/3d_models/Pudelko/Pudelko_Napis_Gora_Lewa.stl
200.0 x 250.0 x 1.00

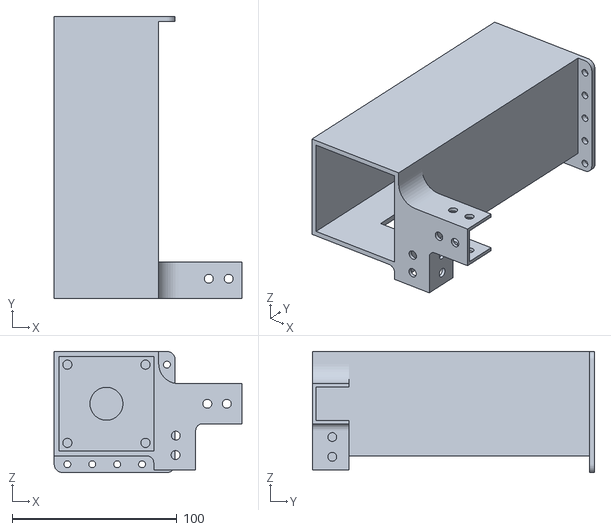
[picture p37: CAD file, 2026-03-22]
docs/projekt/Podstawa_Silnika_Lewa.stl
113.8 x 171.0 x 73.4

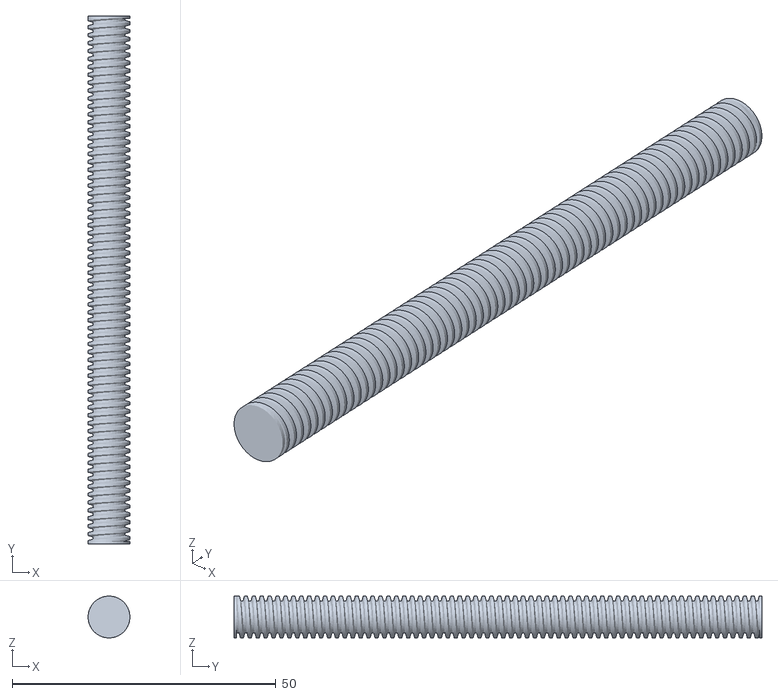
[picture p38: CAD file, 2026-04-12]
application/simulation/src/robot_description/meshes/sruba.stl
7.93 x 100.0 x 7.93

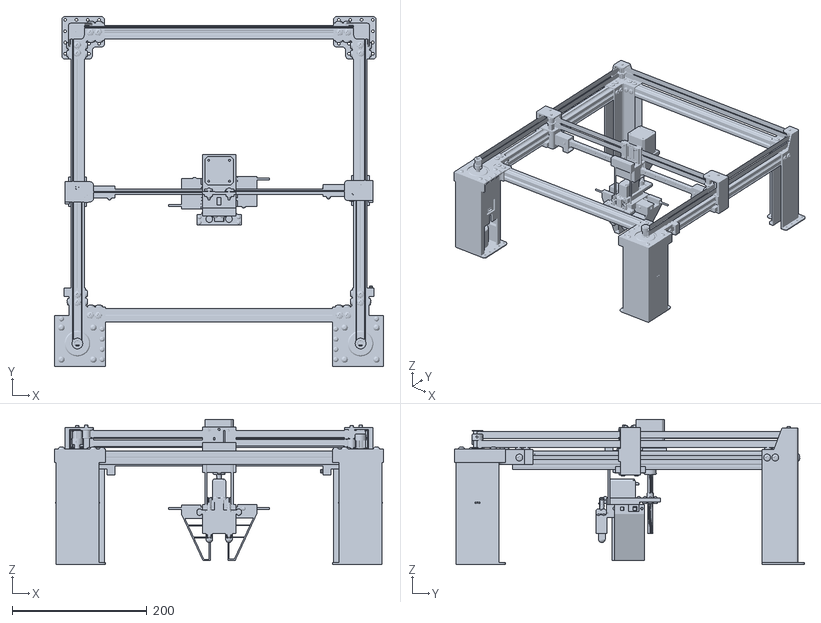
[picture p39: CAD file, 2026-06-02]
docs/3d_models/Montaz_Robota.stl
488.6 x 519.6 x 215.7

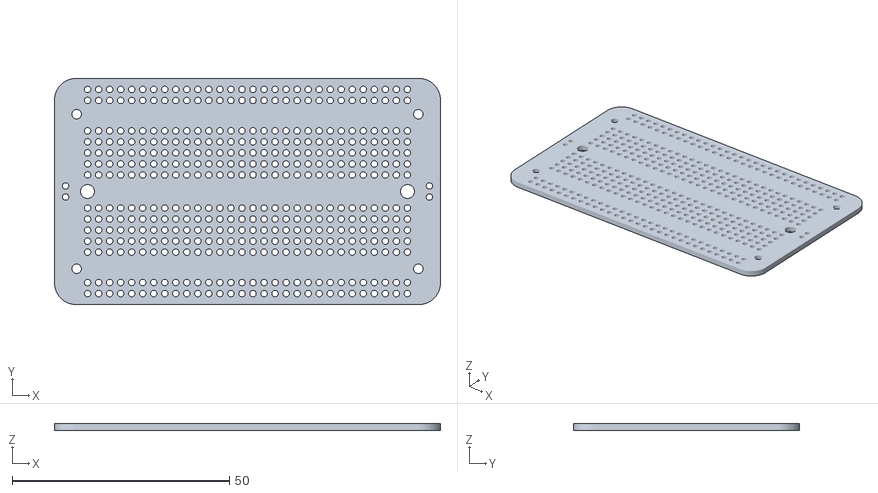
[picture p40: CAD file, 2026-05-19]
docs/3d_models/Pudelko/Electronic_Parts/Prototype_Board.stl
88.9 x 52.1 x 1.60

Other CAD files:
docs/3d_models/Pudelko/Pudelko_Sciana_Lewa.stl
docs/projekt/Mocowanie_Wozek_Prawy.stl
application/simulation/src/robot_description/meshes/naorznik.stl
docs/3d_models/Przykrecenie_Silnika_Lewy.stl
application/simulation/src/robot_description/meshes/Montaz_Robota.stl
application/simulation/src/robot_description/meshes/chwytak.stl
application/simulation/src/robot_description/meshes/listwa_zebata.stl
application/simulation/src/robot_description/meshes/monter_chwytak.stl
application/simulation/src/robot_description/meshes/monter_lewy.stl
application/simulation/src/robot_description/meshes/monter_paski.stl
application/simulation/src/robot_description/meshes/monter_prawy.stl
application/simulation/src/robot_description/meshes/monter_z.stl
application/simulation/src/robot_description/meshes/nakretka.stl
application/simulation/src/robot_description/meshes/nema17.stl
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

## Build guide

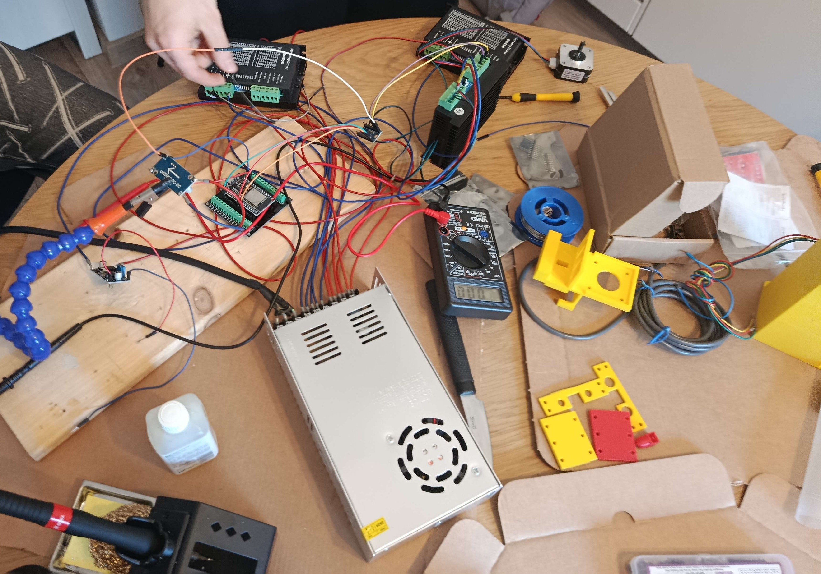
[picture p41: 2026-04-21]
docs/assembly_media/04.11/3.jpg

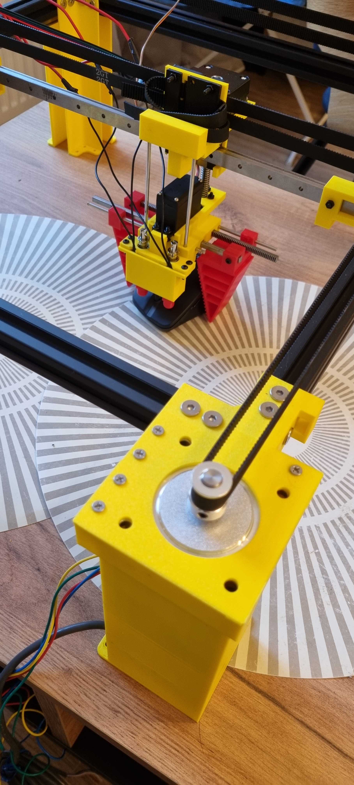
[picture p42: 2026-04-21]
docs/assembly_media/04.17/17_04_1.jpg

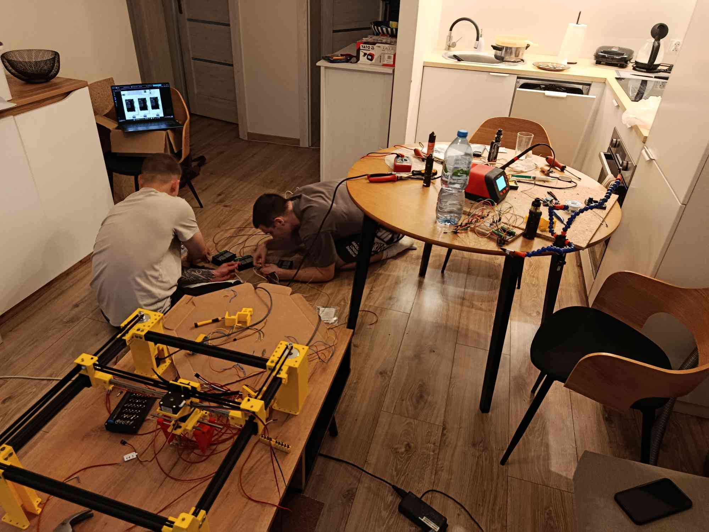
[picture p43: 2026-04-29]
docs/assembly_media/04.25/25_04_2.jpg

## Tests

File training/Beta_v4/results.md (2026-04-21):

# Milestone 2: Konstrukcja i sterowanie ręczne

**Moduł:** M2 - Software (Aplikacja i integracja wejścia)
**Cel:** Aplikacja PC czytająca klawiaturę i wysyłająca komendy do mikrokontrolera, symulacja w Gazebo, kompensacja odrzutu broni.

### Weryfikacja Wymagań (Warunki przejścia)

- [x] **Rozmiar datasetu min. 10 000 zdjęć:** Zgromadzono **10 835** oznaczonych zdjęć (wersja v4.0), co z nadwyżką spełnia cel.
- [x] **Skuteczność YOLO > 95%:** Osiągnięto średnio **97.8%** mAP50 dla wszystkich klas, co znacząco przewyższa wymagany próg.
- [x] **Opóźnienie komunikacji (Latency) < 5 ms:** Osiągnięto **3.14** ms na linii PC -> Mikrokontroler (Baudrate: 115200).
- [x] **Zgubione ramki ~0% (na 10 000 prób):** Zarejestrowano **0** zgubionych ramek.

---

### 1. Komunikacja PC -> Mikrokontroler (UART)

Przeprowadzono analizę logów z timestampami wysłania paczki danych oraz potwierdzenia jej odbioru. 
* **Protokół i prędkość:** UART, 115200 baud
* **Średnie opóźnienie (Latency):** 3.14 ms
* **Maksymalne opóźnienie:** 3.30 ms
* **Ilość prób testowych:** 10 000 wysłanych pakietów
* **Skuteczność dostarczenia (Packet Loss):** 100%

### 2. Aplikacja PC i Logika Sterowania

Aplikacja integruje wejście użytkownika oraz przetwarza dane z modelu detekcji, realizując następujące założenia:
* **Czytanie klawiatury:** Zaimplementowano bez opóźnień asynchroniczne odczytywanie wciśnięć klawiszy sterujących.
* **Kompensacja odrzutu broni (Recoil Control):** [DO ZROBIENIA].
* **Symulacja (Gazebo):** Zrobiona.

---

### 3. Wyniki Detekcji Wizyjnej (YOLO)

Zbiór danych został pomyślnie rozbudowany do wymaganych rozmiarów, a zoptymalizowany model (YOLO26n) wykazuje rewelacyjną skuteczność przy zachowaniu minimalnych opóźnień.

**Wydajność modelu:**
* **Sprzęt testowy:** Intel Core i7-13700KF, 32GB RAM, RTX 5070 Ti
* **Czas przetwarzania (Pipeline):** 1.8 ms (0.3 ms pre + 1.3 ms inferencja + 0.2 ms post)
* **Szacowany FPS (sam model):** ~555 FPS

**Skuteczność detekcji (Wybrane klasy):**

| Klasa | Precyzja (P) | Skuteczność (mAP50) |
| :--- | :---: | :---: |
| **Wszystkie (all)** | **95.8%** | **97.8%** |
| **Terrorysta (tt)** | 96.0% | 97.8% |
| **Antyterrorysta (ct)** | 95.6% | 96.8% |
| **Głowa TT / CT** | 96.5% / 94.5% | 97.2% / 95.6% |
| **Bronie (Rifle, Pistol, etc.)** | > 91.0% | > 97.8% |

**Dataset:**
* **Ilość zdjęć:** 10 835
* **Źródło:** [CSGO Dataset v4 (Roboflow)](https://universe.roboflow.com/ukaszs-workspace/csgo-dataset/dataset/4)

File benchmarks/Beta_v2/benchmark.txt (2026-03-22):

===== BETA 2.0 MODEL BENCHMARK (YOLO26n) =====

    GPU: NVIDIA RTX 5070Ti (PCIe 5.0)
    CPU: INTEL i7-13700KF (24 Cores)
    RAM: 32GB DDR5 6000Mhz

==============================================
    FULL GPU LOOP
----------------------------------------------

    Average time: 3.63 ms
    Fastest loop: 2.90 ms
    Slowest loop: 4.93 ms
    Average grab time: 0.75 ms
    Average tensor conversion time: 0.13 ms
    Average inference time: 2.74 ms

==============================================
    CPU PINNED MEMORY LOOP
----------------------------------------------

    Average time: 3.26 ms
    Fastest loop: 2.77 ms
    Slowest loop: 5.41 ms
    Average grab time: 0.19 ms
    Average tensor conversion time: 0.39 ms
    Average inference time: 2.69 ms
    
==============================================

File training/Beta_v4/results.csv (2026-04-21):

epoch | time | train/box_loss | train/cls_loss | train/dfl_loss | metrics/precision(B) | metrics/recall(B) | metrics/mAP50(B) | metrics/mAP50-95(B) | val/box_loss | val/cls_loss | val/dfl_loss | lr/pg0 | lr/pg1 | lr/pg2 | lr/pg3 | lr/pg4 | lr/pg5 | lr/pg6 | lr/pg7
1 | 123.278 | 1.38069 | 7.08059 | 0.00726 | 0.64621 | 0.59663 | 0.65012 | 0.42999 | 1.33074 | 1.3785 | 0.00766 | 0.0099631 | 0.00332103 | 0.0099631 | 0.00332103 | 0.0099631 | 0.00332103 | 0.0099631 | 0.00332103
2 | 235.065 | 1.32647 | 1.82959 | 0.0069 | 0.78071 | 0.74669 | 0.81349 | 0.54542 | 1.32495 | 1.02119 | 0.00783 | 0.0198972 | 0.00663241 | 0.0198972 | 0.00663241 | 0.0198972 | 0.00663241 | 0.0198972 | 0.00663241
3 | 359.592 | 1.3686 | 1.14225 | 0.00724 | 0.77059 | 0.69095 | 0.77408 | 0.50098 | 1.4877 | 1.12853 | 0.00852 | 0.0297653 | 0.00992178 | 0.0297653 | 0.00992178 | 0.0297653 | 0.00992178 | 0.0297653 | 0.00992178
4 | 463.107 | 1.42588 | 1.08137 | 0.00778 | 0.73395 | 0.62684 | 0.72558 | 0.45867 | 1.50662 | 1.29272 | 0.01021 | 0.029703 | 0.009901 | 0.029703 | 0.009901 | 0.029703 | 0.009901 | 0.029703 | 0.009901
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

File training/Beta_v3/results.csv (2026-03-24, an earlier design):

epoch | time | train/box_loss | train/cls_loss | train/dfl_loss | metrics/precision(B) | metrics/recall(B) | metrics/mAP50(B) | metrics/mAP50-95(B) | val/box_loss | val/cls_loss | val/dfl_loss | lr/pg0 | lr/pg1 | lr/pg2 | lr/pg3 | lr/pg4 | lr/pg5 | lr/pg6 | lr/pg7
1 | 87.8719 | 1.3873 | 8.095 | 0.00772 | 0.62858 | 0.45058 | 0.5012 | 0.35212 | 1.18028 | 1.64449 | 0.00654 | 0.00993939 | 0.00331313 | 0.00993939 | 0.00331313 | 0.00993939 | 0.00331313 | 0.00993939 | 0.00331313
2 | 147.865 | 1.34313 | 2.68225 | 0.00741 | 0.71757 | 0.67966 | 0.73818 | 0.51526 | 1.22365 | 1.10266 | 0.00661 | 0.0198736 | 0.00662453 | 0.0198736 | 0.00662453 | 0.0198736 | 0.00662453 | 0.0198736 | 0.00662453
3 | 197.767 | 1.36138 | 1.4094 | 0.00766 | 0.74167 | 0.65144 | 0.7476 | 0.46997 | 1.45376 | 1.35622 | 0.00978 | 0.0297418 | 0.00991393 | 0.0297418 | 0.00991393 | 0.0297418 | 0.00991393 | 0.0297418 | 0.00991393
4 | 247.342 | 1.40706 | 1.1731 | 0.00803 | 0.7255 | 0.71524 | 0.77946 | 0.52538 | 1.42934 | 1.18091 | 0.0085 | 0.029703 | 0.009901 | 0.029703 | 0.009901 | 0.029703 | 0.009901 | 0.029703 | 0.009901
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

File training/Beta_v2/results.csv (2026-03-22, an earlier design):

epoch | time | train/box_loss | train/cls_loss | train/dfl_loss | metrics/precision(B) | metrics/recall(B) | metrics/mAP50(B) | metrics/mAP50-95(B) | val/box_loss | val/cls_loss | val/dfl_loss | lr/pg0 | lr/pg1 | lr/pg2
1 | 80.7297 | 1.4449 | 9.18889 | 0.00862 | 0.58762 | 0.41837 | 0.40396 | 0.2569 | 1.33339 | 1.82547 | 0.00775 | 0.000276908 | 0.000276908 | 0.000276908
2 | 121.096 | 1.3413 | 5.41386 | 0.00773 | 0.68285 | 0.56088 | 0.59564 | 0.4 | 1.25177 | 1.36525 | 0.00707 | 0.000549084 | 0.000549084 | 0.000549084
3 | 168.741 | 1.31586 | 3.18368 | 0.0075 | 0.75913 | 0.63406 | 0.69621 | 0.4925 | 1.21642 | 1.1711 | 0.0063 | 0.000815763 | 0.000815763 | 0.000815763
4 | 242.936 | 1.31592 | 2.03041 | 0.00752 | 0.80481 | 0.62813 | 0.76612 | 0.52912 | 1.24073 | 1.10057 | 0.00704 | 0.00080826 | 0.00080826 | 0.00080826
5 | 311.427 | 1.26452 | 1.49147 | 0.00709 | 0.8022 | 0.76968 | 0.83697 | 0.58086 | 1.23014 | 0.97237 | 0.00645 | 0.000800013 | 0.000800013 | 0.000800013
6 | 352.256 | 1.2636 | 1.22214 | 0.00699 | 0.75528 | 0.78864 | 0.83046 | 0.59355 | 1.18793 | 0.92366 | 0.00616 | 0.000791767 | 0.000791767 | 0.000791767
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

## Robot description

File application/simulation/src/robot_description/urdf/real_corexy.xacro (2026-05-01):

<?xml version="1.0"?>
<robot name="my_robot" xmlns:xacro="http://www.ros.org/wiki/xacro">

    <xacro:property name="base_width" value="0.5178" />
    <xacro:property name="base_length" value="0.4838" />
    <xacro:property name="base_height" value="0.01" />


    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

    <xacro:include filename="$(find robot_description)/urdf/links_macro.xacro"/>

    <xacro:pret_fi5 prefix="1" />
    <xacro:pret_fi5 prefix="2" />
    <xacro:pret_fi5 prefix="3" />
    <xacro:pret_fi5 prefix="4" />
    <xacro:pret_fi5 prefix="5" />
    <xacro:pret_fi5 prefix="6" />

    <xacro:rolka_gladka prefix="a"/>
    <xacro:rolka_gladka prefix="b"/>

    <xacro:rolka_zebata prefix="a_1"/>
    <xacro:rolka_zebata prefix="a_2"/>
    <xacro:rolka_zebata prefix="a_3"/>

    <xacro:rolka_zebata prefix="b_1"/>
    <xacro:rolka_zebata prefix="b_2"/>
    <xacro:rolka_zebata prefix="b_3"/>

    <xacro:pret_fi3 prefix="1" origin_xyz="0.0125 -0.025 -0.013" origin_rpy="0 0 0" />
    <xacro:pret_fi3 prefix="2" origin_xyz="0.0516 0.025 -0.013" origin_rpy="0 0 ${pi}" />
    <xacro:pret_fi3 prefix="3" origin_xyz="0.0394 0.0195 0.02" origin_rpy="${-pi/2.0} 0 0" />
    <xacro:pret_fi3 prefix="4" origin_xyz="0.0394 -0.0195 0.02" origin_rpy="${-pi/2.0} 0 0" />

    
    <link name="base_link">
        <inertial>
            <origin xyz="0 0 ${base_height/2.0}" rpy="0 0 0"/>
            <mass value="10"/>
            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
        </inertial>
        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
    </link>

    <link name="podstawa_prawa">
        <inertial>
            <origin xyz="0 0.042 0.167" rpy="${-pi/2.0} 0 ${-pi/2.0}" />
            <mass value="0.11223308489437728" />
            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
        </inertial>
        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
    </link>

    <link name="podstawa_lewa">
        <inertial>
            <origin xyz="-0.042 0 0.167" rpy="${-pi/2.0} 0 0" />
            <mass value="0.11223308489437728" />
            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
        </inertial>
        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
    </link>


    <link name="podstawa_silnik_prawa">
        <inertial>
            <origin xyz="0 0 0.169" rpy="${-pi/2.0} 0 ${pi}" />
            <mass value="2.03711e-01"/>
            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    
        </inertial>
        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
    </link>

    <link name="podstawa_silnik_lewa">
        <inertial>
            <origin xyz="0 0 0.169" rpy="${-pi/2.0} 0 ${pi}" />
            <mass value="2.03711e-01"/>
            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
        </inertial>
        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
    </link>


    <link name="nema23_prawa">
        <inertial>
            <origin xyz="0 0 0" rpy="${pi/2.0} 0 0" />
            <mass value="1.8783499708303255" />
            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
        </inertial>
        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
    </link>

    <link name="nema23_lewa">
        <inertial>
            <origin xyz="0 0 0" rpy="${pi/2.0} 0.0 0.0" />
            <mass value="1.8783499708303255" />
            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
        </inertial>
        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
    </link>

    <link name="profil_przod">
        <inertial>
            <origin xyz="-0.042 0.01 -0.012" rpy="0.0 0.0 0.0" />
            <mass value="0.19670492898970188" />
            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
        </inertial>
        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
    </link>

    <link name="profil_tyl">
        <inertial>
            <origin xyz="0 -0.011 -0.012" rpy="0.0 -0.0 ${pi}" />
            <mass value="0.19670492898970188" />
            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
        </inertial>
        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
    </link>

    <link name="profil_prawy">
        <inertial>
            <origin xyz="-0.053 0 -0.012" rpy="0 0 ${pi/2.0}" />
            <mass value="0.19670492898970188" />
            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
        </inertial>
        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
    </link>

    <link name="profil_lewy">
        <inertial>
            <origin xyz="0.01 0 -0.012" rpy="0.0 -0.0 ${-pi/2.0}" />
            <mass value="0.19670492898970188" />
            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
        </inertial>
        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
    </link>

    <link name="szyna_prawa">
        <inertial>
            <origin xyz="-0.053 0 -0.022" rpy="0 ${pi} ${-pi/2.0}" />
            <mass value="0.09347154569423409" />
            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
        </inertial>
        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
    </link>
    <link name="szyna_lewa">
        <inertial>
            <origin xyz="0.01 0 -0.022" rpy="0 ${pi} ${pi/2.0}" />
            <mass value="0.09347154569423409" />
            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
        </inertial>
        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
    </link>

     <link name="zebatka_napedowa_prawa">
        <inertial>
            <origin xyz="0 0 0.005" rpy="0 0 0" />
            <mass value="0.005385408521332733" />
            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
        </inertial>
        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
    </link>
    <link name="zebatka_napedowa_lewa">
        <inertial>
            <origin xyz="0 0 0.024" rpy="${pi} 0 0" />
            <mass value="0.005385408521332733" />
            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
        </inertial>
        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
    </link>

    <link name="przykrecenie_prawe">
        <inertial>
            <origin xyz="0.0 0.0 -0.002" rpy="${pi/2.0} ${pi} 0" />
            <mass value="1.4997e-02"/>
            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
        </inertial>
        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
    </link>

    <link name="przykrecenie_lewe">
        <inertial>
            <origin xyz="0.0 0.0 -0.002" rpy="${pi/2.0} ${pi} ${pi}" />
            <mass value="1.4997e-02"/>
            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
        </inertial>
        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
    </link>

     <link name="wozek_lewy">
        <inertial>
            <origin xyz="0 0 -0.035" rpy="${pi} 0 ${pi/2.0}" />
            <mass value="0.02072744141690809" />
            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
        </inertial>
        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
    </link>

    <link name="monter_lewy"> 
        <inertial>
            <origin xyz="0 0 -0.034" rpy="${pi/2.0} ${pi} ${pi/2.0}" />
            <mass value="4.4339e-02"/>
            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
        </inertial>
        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
    </link>

    <link name="szyna_srodek">
        <inertial>
            <origin xyz="0.004 -0.04 -0.018" rpy="0 ${pi/2.0} ${pi}" />
            <mass value="0.09005351776720373" />
            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
        </inertial>
        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
    </link>

    <link name="monter_prawy"> 
        <inertial>
            <origin xyz="0 0 -0.034" rpy="${-pi/2.0} 0 ${pi/2.0}" />
            <mass value="4.4339e-02"/>
            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
        </inertial>
        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
    </link>

     <link name="wozek_prawy">  
        <inertial>
            <origin xyz="0 0 -0.035" rpy="${pi} 0 ${pi/2.0}" />
            <mass value="0.02072744141690809" />
            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
        </inertial>
        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
    </link>

    <link name="wozek_srodek">
        <inertial>
            <origin xyz="0 0 0" rpy="0 ${pi/2.0} ${pi}" />
            <mass value="0.02072744141690809" />
            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
        </inertial>
        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
    </link>

    <link name="monter_srodek">
        <inertial>
            <origin xyz="0 0 0" rpy="0 0 ${pi/2.0}" />
            <mass value="3.84902e-01"/>
            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
        </inertial>
        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
    </link>

    <link name="nema17">
        <inertial>
            <origin xyz="0.0 0.0 0.0165" rpy="${-pi/2.0} 0 0" />
            <mass value="3.26909e-01"/>
            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
        </inertial>
        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
    </link>

    <link name="monter_paski">
        <inertial>
            <origin xyz="0 0 0" rpy="0 0 ${pi/2.0}" />
            <mass value="5.526e-03"/>
            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
        </inertial>
        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
    </link>

    <link name="sprzeglo">
        <inertial>
            <origin xyz="0 0 0" rpy="${-pi/2.0} 0 0" />
            <mass value="1.3571e-02"/>
            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
        </inertial>
        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
    </link>

    <link name="sruba">
        <inertial>
            <origin xyz="0 0 -0.112" rpy="${pi/2.0} 0 0" />
            <mass value="3.0946e-02"/>
            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
        </inertial>
        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
    </link>

    <link name="nakretka">
        <inertial>
            <origin xyz="0 0 0" rpy="${-pi/2.0} 0 0" />
            <mass value="8.379933e-03"/>
            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
        </inertial>
        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
    </link>

    <link name="monter_chwytak">
        <inertial>
            <origin xyz="0 0 0" rpy="${-pi/2.0} ${pi} ${-pi/2.0}" />
            <mass value="6.961e-02"/>
            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
        </inertial>
        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
    </link>

    <link name="zebatka_serwo">
        <inertial>
            <origin xyz="0 0 0" rpy="0 0 0" />
            <mass value="2.548e-03"/>
            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
        </inertial>
        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
    </link>
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

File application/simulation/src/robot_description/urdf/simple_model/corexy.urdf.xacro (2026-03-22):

<?xml version="1.0"?>
<robot name="my_robot" xmlns:xacro="http://www.ros.org/wiki/xacro">

    <xacro:include filename="$(find robot_description)/urdf/properties.xacro"/>
    <xacro:include filename="$(find robot_description)/urdf/macro.xacro"/>
    
    <link name="base_link">
        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
        <xacro:box_inertia m="5.0" w="${base_width}" l="${base_length}" h="${base_height}" xyz="0 0 ${base_height/2.0}" rpy="0 0 0"/>
    </link>

    <link name="motorA_link">
        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
        <xacro:cylinder_inertia m="0.5" r="${motor_radius}" h="${motor_height}" xyz="0 0 ${motor_height/2.0}" rpy="0 0 0"/>
    </link>

    <link name="motorB_link">
        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
        <xacro:cylinder_inertia m="0.5" r="${motor_radius}" h="${motor_height}" xyz="0 0 ${motor_height/2.0}" rpy="0 0 0"/>
    </link>

    <link name="railA_link">
        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
        <xacro:box_inertia m="0.5" w="${base_length-2.0*motor_radius}" l="${rail_width}" h="${rail_length}" xyz="${motor_radius} 0 ${rail_length/2.0}" rpy="0 0 0"/>
    </link>

     <link name="railA_supp_link">
        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
        <xacro:box_inertia m="1.0" w="${base_length}" l="${rail_width}" h="${rail_length*2.0}" xyz="0 0 ${rail_length}" rpy="0 0 0"/>
    </link>

    <link name="railB_link">
        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
        <xacro:box_inertia m="0.5" w="${base_length-2.0*motor_radius}" l="${rail_width}" h="${rail_length}" xyz="${motor_radius} 0 ${rail_length/2.0}" rpy="0 0 0"/>
    </link>

    <link name="railB_supp_link">
        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
        <xacro:box_inertia m="1.0" w="${base_length}" l="${rail_width}" h="${rail_length*2.0}" xyz="0 0 ${rail_length}" rpy="0 0 0"/>
    </link>

    <link name="main_rail_link">
        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
        <xacro:box_inertia m="0.5" w="${main_rail_size}" l="${base_length-2.0*rail_length}" h="${main_rail_size}" xyz="0 ${(base_length-2.0*rail_length)/2.0} 0" rpy="0 0 0"/>
    </link>

    <link name="carriage_link">
        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
        <xacro:box_inertia m="0.2" w="${carriage_length}" l="${carriage_width}" h="${carriage_height}" xyz="0 0 ${carriage_height/2.0}" rpy="0 0 0"/>
    </link>

    <link name="gripper_link">
        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
        <xacro:box_inertia m="0.05" w="${gripper_width}" l="${gripper_length}" h="${gripper_height}" xyz="${gripper_length / 2.0} 0 0" rpy="0 0 0"/>
    </link>

    <joint name="motorA_joint" type="continuous">
        <parent link="railA_supp_link"/>
        <child link="motorA_link"/>
        <origin xyz="${-base_width/2.0 + motor_radius} 0 ${rail_length*2.0}" rpy="0 0 0" />
        <axis xyz="0 0 1"/>
        <dynamics damping="0.4" friction="0.05"/>
        <limit effort="100" velocity="30"/>
    </joint>

    <joint name="motorB_joint" type="continuous">
        <parent link="railB_supp_link"/>
        <child link="motorB_link"/>
        <origin xyz="${-base_width/2.0 + motor_radius} 0 ${rail_length*2.0}" rpy="0 0 0" />
        <axis xyz="0 0 1"/>
        <dynamics damping="0.4" friction="0.05"/>
        <limit effort="100" velocity="30"/>
    </joint>

    <joint name="base_railA_supp_joint" type="fixed">
        <parent link="base_link"/>
        <child link="railA_supp_link"/>
        <origin xyz="0 -${base_width/2.0-rail_width/2.0} ${base_height}" rpy="0 0 0" />
    </joint>

     <joint name="base_railB_supp_joint" type="fixed">
        <parent link="base_link"/>
        <child link="railB_supp_link"/>
        <origin xyz="0 ${base_width/2.0-rail_width/2.0} ${base_height}" rpy="0 0 0" />
    </joint>

     <joint name="railA_supp_joint" type="fixed">
        <parent link="railA_supp_link"/>
        <child link="railA_link"/>
        <origin xyz="0 0 ${rail_length*2.0}" rpy="0 0 0" />
    </joint>

     <joint name="railB_supp_joint" type="fixed">
        <parent link="railB_supp_link"/>
        <child link="railB_link"/>
        <origin xyz="0 0 ${rail_length*2.0}" rpy="0 0 0" />
    </joint>

     <joint name="x_axis_joint" type="prismatic">
        <parent link="railA_link"/>
        <child link="main_rail_link"/>
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

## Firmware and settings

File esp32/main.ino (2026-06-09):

/*
 * CoreXY motor control firmware - predictive tracking workspace version.
 * ESP32-based controller for a CoreXY robotic platform with a Z-axis servo.
 * Limit switches are debounced and used for XY homing and safety.
 * The Z-limit is intentionally ignored in the default workspace logic.
 * Virtual software endstops are configured to 28 cm on X and 24 cm on Y from the origin.
 */

#include <ESP32Servo.h>
#include <ESP32Encoder.h>

// ============================================================================
// Non-blocking debounce state.
// Keep this near the top of the .ino file. Arduino generates function
// prototypes automatically, and custom types must already be known.
// ============================================================================

struct DebouncedInputState {
  bool stablePressed;
  bool lastRawPressed;
  unsigned long lastChangeMs;
};

DebouncedInputState limitXDebounce = {false, false, 0};
DebouncedInputState limitYDebounce = {false, false, 0};


// ============================================================================
// Pin definitions.
// ============================================================================

#define PUL1_PIN 23
#define DIR1_PIN 22
#define PUL2_PIN 21
#define DIR2_PIN 19
#define PULZ_PIN 12
#define DIRZ_PIN 17

#define SERVO_PIN 25
#define RELAY1_PIN 27
#define RELAY2_PIN 26

#define ENCO1_PHASE_A 18
#define ENCO1_PHASE_B 5
#define ENCO2_PHASE_A 32
#define ENCO2_PHASE_B 33

#define LIMIT_X_PIN 4
#define LIMIT_Y_PIN 13
#define LIMIT_Z_PIN 14

// ============================================================================
// Serial command buffer for emergency stop.
// ============================================================================

const int MAX_BUFFER_SIZE = 64;
char serialBuffer[MAX_BUFFER_SIZE];
int bufferIndex = 0;
bool isCommandReady = false;
int targetDetected = 0;

// Statistics tracking
float totalDistanceCm = 0.0;
float lastPosX = 0.0;
float lastPosY = 0.0;
unsigned long lastStatsSentMs = 0;
const unsigned long STATS_SEND_INTERVAL_MS = 5000;

// LMB/RMB click tracking
unsigned long totalLmbClicks = 0;
unsigned long totalRmbClicks = 0;
bool lastFireOutputState = false;
bool lastScopeOutputState = false;

// ============================================================================
// Configurable parameters and state variables.
// ============================================================================

int delayCoreXY = 600;
const int delayZ = 50;
int homingDelay = 600;

bool motor1Running = false;
bool motor2Running = false;
bool motorZRunning = false;

// Tracks active movement for continuous endstop monitoring.
bool isMovingUp = false;
bool isMovingDown = false;
bool isMovingLeft = false;
bool isMovingRight = false;

ESP32Encoder encoder1;
ESP32Encoder encoder2;

float currentPosX = 0.0;
float currentPosY = 0.0;
unsigned long lastEncoderPrint = 0;

float stepsPerCM = 296.30;
float skewAngleX = 0.0;
float skewAngleY = 0.0;

long currentZSteps = 0;
long stepsForZDrop = 5800;
bool wasLimitZPressed = false;
bool isZUp = false;

// ============================================================================
// Encoder axis sign calibration.
// ============================================================================
//
// Actual motion mapping in this setup:
// - Moving left increases X.
// - Moving right decreases X.
// - Moving down increases Y.
// - Moving up decreases Y.
//
// If the axes move in reverse, change SIGN_X or SIGN_Y from 1 to -1.

const int SIGN_X = 1;
const int SIGN_Y = -1;

// ============================================================================
// Servo settings.
// ============================================================================

Servo mainServo;
bool servoState = false;
unsigned long lastServoToggle = 0;

const int angleUp = 0;
const int angleDown = 180;

unsigned long servoMoveStartTime = 0;
bool isServoTimerActive = false;
unsigned long lastLimitNotify = 0;

// ============================================================================
// Virtual workspace limits.
// ============================================================================
//
// After homing and back-off:
// X ranges from 0.00 cm to 24.50 cm.
// Y ranges from 0.00 cm to 28.50 cm.

const float LIMIT_MIN_X = 0.00;
const float LIMIT_MAX_X = 24.50;
const float LIMIT_MIN_Y = 0.00;
const float LIMIT_MAX_Y = 28.50;
const float LIMIT_MARGIN_CM = 0.30;

// ============================================================================
// Auto-recovery settings.
// ============================================================================
//
// When XY reaches a software limit:
// 1. Save the current Z position.
// 2. Raise Z quickly.
// 3. Move XY toward the center at the same time.
// 4. After half of the XY path is complete, lower Z back to the saved position.

bool isAutoRecovering = false;

const float CENTER_TOLERANCE_CM = 0.20;

const int RECOVERY_XY_DELAY = 350;
const int RECOVERY_Z_DELAY = 220;

const long MAX_Z_RECOVERY_STEPS = 9000;
const unsigned long MAX_RECOVERY_TIME_MS = 12000;

int posX = 0;
int posY = 0;
String pressedKeys = "";
bool isManualJogging = false;
float jogVM1 = 0.0;
float jogVM2 = 0.0;
int jogDirM1 = LOW;
int jogDirM2 = LOW;
float manualAccumM1 = 0.0;
float manualAccumM2 = 0.0;

// ============================================================================
// Vision PD control settings.
// ============================================================================

int targetOffsetPxX = 0;
int targetOffsetPxY = 0;
int isHoldingSniper = 0;
int maxSpeedValue = 100;

bool visionControlActive = false;

float visionTargetX = 0.0;
float visionTargetY = 0.0;

float pxToCmX = 0.0021167; // to be calibrated based on eDPI (current 1200)
float pxToCmY = 0.0021167; // ... = 1px * 2.54 / eDPI

float kpVision = 55.0;
float kiVision = 0.0;  // Start with PD for moving targets. Add I only for slow static bias.
float kdVision = 6.0;

float prevVisionErrorX = 0.0;
float prevVisionErrorY = 0.0;

float integralErrorX = 0.0; // Accumulated integral error X
float integralErrorY = 0.0; // Accumulated integral error Y
const float maxIntegral = 50.0; // Anti-windup limit for integral term

unsigned long lastVisionPidMicros = 0;

float filteredOffsetX = 0.0;
float filteredOffsetY = 0.0;
const float VISION_FILTER_ALPHA = 0.70; // higher = less lag; lower = smoother

int visionDeadzonePxX = 5;
int visionDeadzonePxY = 5;

const float VISION_TARGET_TOLERANCE_CM = 0.01;

// Predictive tracking and speed-shaping settings.
// lookahead compensates camera/inference/serial/mechanical latency.
float visionLookaheadSec = 0.000;       // stable default: no prediction; tune up slowly
float kvVisionPx = 0.00;                // stable default: no velocity feed-forward; tune up slowly
float filteredTargetVelPxX = 0.0;
float filteredTargetVelPxY = 0.0;
const float TARGET_VEL_FILTER_ALPHA = 0.35;
float prevRotatedOffsetX = 0.0;
float prevRotatedOffsetY = 0.0;
bool hasPrevRotatedOffset = false;

const float MAX_DERIVATIVE_CM_S = 5.0;  // derivative clamp in cm/s

// Runtime-tunable tracking parameters. These can be changed from the PC GUI
// with: TUNE,<outputDeadband>,<minTrackingSpeedPercent>,<visionAccelLimitPercent>
float outputDeadband = 0.9;             // larger deadband improves stability
int minTrackingSpeedPercent = 3;        // minimum speed while tracking
int visionAccelLimitPercent = 10;       // max speed-percent change per control update
int currentVisionSpeedPercent = 0;

unsigned long centeredSinceMs = 0;
const unsigned long CENTER_STABLE_STOP_MS = 80;


// ============================================================================
// Vision-centered event tracking.
// ============================================================================

bool wasVisionCentered = false;
unsigned long lastVisionCenteredEventMs = 0;
const unsigned long VISION_CENTERED_COOLDOWN_MS = 250;

// ============================================================================
// Fire control settings.
// ============================================================================

// Rifle settings
const unsigned long RIFLE_HOLD_MS = 70;
const unsigned long RIFLE_GAP_MS = 250;

// Sniper settings
const unsigned long SNIPER_SCOPE_DELAY_MS = 35; // Quickscope delay
const unsigned long SNIPER_HOLD_MS = 50;        // Click duration
const unsigned long SNIPER_COOLDOWN_MS = 1600;  // Strict lockout to ignore dead bodies

bool fireRequestActive = false;
bool manualScopeRequestActive = false;

// State trackers
bool fireOutputActive = false;
bool scopeOutputActive = false;
unsigned long fireSequenceStartMs = 0;
unsigned long lastFireEndMs = 0;

// ============================================================================
// Forward declarations of functions defined later in the code.
// ============================================================================

bool checkEmergencyStop();

// ============================================================================
// Motor control helpers.
// ============================================================================

void stopAllMotors() {
  motor1Running = false;
  motor2Running = false;
  motorZRunning = false;
  jogVM1=0.0;
  jogVM2=0.0;
  isManualJogging = false;
  currentVisionSpeedPercent=0;

  isMovingUp = false;
  isMovingDown = false;
  isMovingLeft = false;
  isMovingRight = false;

  digitalWrite(PUL1_PIN, LOW);
  digitalWrite(PUL2_PIN, LOW);
  digitalWrite(PULZ_PIN, LOW);
}

void setMotorsXY(bool run1, int dir1, bool run2, int dir2) {
  motorZRunning = false;

  if (run1) digitalWrite(DIR1_PIN, dir1);
  if (run2) digitalWrite(DIR2_PIN, dir2);

  delayMicroseconds(5);

  motor1Running = run1;
  motor2Running = run2;
}

void moveZ(int dirZ) {
  motor1Running = false;
  motor2Running = false;

  digitalWrite(DIRZ_PIN, dirZ);
  delayMicroseconds(5);

  motorZRunning = true;
}

// ============================================================================
// Debounce helper for limit switches.
// ============================================================================

bool isSwitchStablyPressed(int pin, unsigned long debounceTimeMs) {
  if (digitalRead(pin) == HIGH) {
    return false;
  }

  unsigned long startMillis = millis();

  while (millis() - startMillis < debounceTimeMs) {
    if (digitalRead(pin) == HIGH) {
      return false;
    }
  }

  return true;
}

// ============================================================================
// Position calculation from encoders.
// ============================================================================

void updateEncoderPosition() {
  long e1Count = encoder1.getCount();
  long e2Count = encoder2.getCount();

  float ticksX = (e1Count + e2Count) / 2.0;
  float ticksY = (e1Count - e2Count) / 2.0;

  currentPosX = (SIGN_X * ticksX / stepsPerCM) + 1.0;
  currentPosY = (SIGN_Y * ticksY / stepsPerCM) + 1.0;
}

void updateTraveledDistance() {
  float dx = currentPosX - lastPosX;
  float dy = currentPosY - lastPosY;
  float distance = sqrt((dx * dx) + (dy * dy));

  totalDistanceCm += distance;

  lastPosX = currentPosX;
  lastPosY = currentPosY;
}

// ============================================================================
// Software workspace limit check.
// ============================================================================

bool isOutsideWorkspace() {
  if (currentPosX <= LIMIT_MIN_X + LIMIT_MARGIN_CM) return true;
  if (currentPosX >= LIMIT_MAX_X - LIMIT_MARGIN_CM) return true;
  if (currentPosY <= LIMIT_MIN_Y + LIMIT_MARGIN_CM) return true;
  if (currentPosY >= LIMIT_MAX_Y - LIMIT_MARGIN_CM) return true;

  return false;
}

// ============================================================================
// Debug output.
// ============================================================================
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
void loop() {

  // Hardware encoder position calculation.

  updateEncoderPosition();

  if (millis() - lastEncoderPrint > 500) {
    long e1Count = encoder1.getCount();
    long e2Count = encoder2.getCount();

    Serial.print("E1: ");
    Serial.print(e1Count);

    Serial.print(" | E2: ");
    Serial.print(e2Count);

    Serial.print(" | X: ");
    Serial.print(currentPosX);

    Serial.print(" | Y: ");
    Serial.print(currentPosY);

    Serial.print(" | Z: ");
    Serial.print(currentZSteps);

    Serial.print(" | L:");
    Serial.print(isMovingLeft);

    Serial.print(" R:");
    Serial.print(isMovingRight);

    Serial.print(" U:");
    Serial.print(isMovingUp);

    Serial.print(" D:");
    Serial.println(isMovingDown);

    lastEncoderPrint = millis();
  }

  // Continuous software workspace limit monitor.

  applyContinuousWorkspaceLimit();

  // The Z limit is intentionally not checked with debounce in the main loop.
  // This allows XY motion to continue normally when the Z endstop is physically pressed.
  // The Z limit is checked only while Z is moving up.

  // Limit switch safety and bounce-back.

  bool limitX = readDebouncedPressed(LIMIT_X_PIN, limitXDebounce, 20);
  bool limitY = readDebouncedPressed(LIMIT_Y_PIN, limitYDebounce, 20);
  bool limitZ = false;

  if (limitX || limitY || limitZ) {
    stopAllMotors();

    Serial.println();
    Serial.println("==================================================");
    Serial.println("WARNING: Limit switch hit! Bouncing back...");
    Serial.print("limitX = ");
    Serial.println(limitX);
    Serial.print("limitY = ");
    Serial.println(limitY);
    Serial.print("currentPosX = ");
    Serial.println(currentPosX, 4);
    Serial.print("currentPosY = ");
    Serial.println(currentPosY, 4);
    Serial.print("E1 = ");
    Serial.println(encoder1.getCount());
    Serial.print("E2 = ");
    Serial.println(encoder2.getCount());
    Serial.println("==================================================");
    Serial.println();

    int bounceSteps = (int)stepsPerCM;
    int bounceDelay = 800;

    if (limitX) {
      digitalWrite(DIR1_PIN, LOW);
      digitalWrite(DIR2_PIN, HIGH);

      for (int i = 0; i < bounceSteps; i++) {
        digitalWrite(PUL1_PIN, HIGH);
        digitalWrite(PUL2_PIN, HIGH);
        delayMicroseconds(bounceDelay);

        digitalWrite(PUL1_PIN, LOW);
        digitalWrite(PUL2_PIN, LOW);
        delayMicroseconds(bounceDelay);
      }
    }

    if (limitY) {
      digitalWrite(DIR1_PIN, LOW);
      digitalWrite(DIR2_PIN, LOW);

      for (int i = 0; i < bounceSteps; i++) {
        digitalWrite(PUL1_PIN, HIGH);
        digitalWrite(PUL2_PIN, HIGH);
        delayMicroseconds(bounceDelay);

        digitalWrite(PUL1_PIN, LOW);
        digitalWrite(PUL2_PIN, LOW);
        delayMicroseconds(bounceDelay);
      }
    }

    stopAllMotors();

    isCommandReady = false;
    bufferIndex = 0;

    delay(200);
  }

  // Servo auto-detach.

  if (isServoTimerActive && (millis() - servoMoveStartTime >= 2000)) {
    mainServo.detach();
    isServoTimerActive = false;
  }

  // Serial command receiving.
  while (Serial.available() > 0 && !isCommandReady) {
    char incomingChar = Serial.read();

    if (incomingChar == '\r' || incomingChar == '\n') {
      serialBuffer[bufferIndex] = '\0';
      isCommandReady = true;
    } else {
      if (bufferIndex < MAX_BUFFER_SIZE - 1) {
        serialBuffer[bufferIndex] = incomingChar;
        bufferIndex++;
      }
    }
  }

  // Command parsing and execution.

  if (isCommandReady) {
    String data = String(serialBuffer);
    data.trim();

    if (data == "ESP32-CHECK") {
      Serial.println("ESP32-READY");
      isCommandReady = false;
      bufferIndex = 0;
    }
    else if (data.substring(0, 12) == "CALIBRATION,") {
      int firstComma = data.indexOf(',', 0);
      int secondComma = data.indexOf(',', firstComma + 1);
      int thirdComma = data.indexOf(',', secondComma + 1);

      if (firstComma > 0 && secondComma > 0 && thirdComma > 0) {
        int calibrated_edpi = data.substring(firstComma + 1, secondComma).toInt();
        skewAngleX = data.substring(secondComma + 1, thirdComma).toFloat();
        skewAngleY = data.substring(thirdComma + 1).toFloat();

        pxToCmX = 1.0 * 2.54 / calibrated_edpi;
        pxToCmY = 1.0 * 2.54 / calibrated_edpi;

        Serial.print("Calibration saved! eDPI: ");
        Serial.print(calibrated_edpi);
        Serial.print(" | SkewX: ");
        Serial.print(skewAngleX, 4);
        Serial.print(" | SkewY: ");
        Serial.println(skewAngleY, 4);
      }
    }
    else if (data.substring(0, 4) == "PID,") {
      int firstComma = data.indexOf(',', 0);
      int secondComma = data.indexOf(',', firstComma + 1);
      int thirdComma = data.indexOf(',', secondComma + 1);

      if (firstComma > 0 && secondComma > 0 && thirdComma > 0) {
        kpVision = data.substring(firstComma + 1, secondComma).toFloat();
        kiVision = data.substring(secondComma + 1, thirdComma).toFloat();
        kdVision = data.substring(thirdComma + 1).toFloat();

        Serial.print("PID updated: Kp=");
        Serial.print(kpVision);
        Serial.print(" Ki=");
        Serial.print(kiVision);
        Serial.print(" Kd=");
        Serial.println(kdVision);
      }
    }
    else if (data.substring(0, 6) == "TRACK,") {
      int firstComma = data.indexOf(',', 0);
      int secondComma = data.indexOf(',', firstComma + 1);

      if (firstComma > 0 && secondComma > 0) {
        visionLookaheadSec = data.substring(firstComma + 1, secondComma).toFloat();
        kvVisionPx = data.substring(secondComma + 1).toFloat();

        if (visionLookaheadSec < 0.0) visionLookaheadSec = 0.0;
        if (visionLookaheadSec > 0.150) visionLookaheadSec = 0.150;
        if (kvVisionPx < 0.0) kvVisionPx = 0.0;
        if (kvVisionPx > 3.0) kvVisionPx = 3.0;

        Serial.print("Tracking updated: lookaheadSec=");
        Serial.print(visionLookaheadSec, 4);
        Serial.print(" KvPx=");
        Serial.println(kvVisionPx, 4);
      }
    }
    else if (data.substring(0, 5) == "TUNE,") {
      int firstComma = data.indexOf(',', 0);
      int secondComma = data.indexOf(',', firstComma + 1);
      int thirdComma = data.indexOf(',', secondComma + 1);

      if (firstComma > 0 && secondComma > 0 && thirdComma > 0) {
        outputDeadband = data.substring(firstComma + 1, secondComma).toFloat();
        minTrackingSpeedPercent = data.substring(secondComma + 1, thirdComma).toInt();
        visionAccelLimitPercent = data.substring(thirdComma + 1).toInt();

        // Safety clamps for stable runtime tuning.
        if (outputDeadband < 0.0) outputDeadband = 0.0;
        if (outputDeadband > 10.0) outputDeadband = 10.0;

        if (minTrackingSpeedPercent < 0) minTrackingSpeedPercent = 0;
        if (minTrackingSpeedPercent > 100) minTrackingSpeedPercent = 100;

        if (visionAccelLimitPercent < 1) visionAccelLimitPercent = 1;
        if (visionAccelLimitPercent > 100) visionAccelLimitPercent = 100;

        Serial.print("Tune updated: deadband=");
        Serial.print(outputDeadband, 3);
        Serial.print(" minSpeed=");
        Serial.print(minTrackingSpeedPercent);
        Serial.print(" accelLimit=");
        Serial.println(visionAccelLimitPercent);
      }
    }
    else if (data.length() > 0) {
      int commaIndexes[7] = {0, 0, 0, 0, 0, 0, 0};
      int commaIndex = 0;

      for (int index = 0; index < data.length(); index++) {
        if (data[index] == ',') {
          if (commaIndex < 7) {
            commaIndexes[commaIndex] = index;
            commaIndex++;
          }
        }
      }

      if (commaIndex == 7) {
        targetOffsetPxX = data.substring(0, commaIndexes[0]).toInt();
        targetOffsetPxY = data.substring(commaIndexes[0] + 1, commaIndexes[1]).toInt();
        isHoldingSniper = data.substring(commaIndexes[1] + 1, commaIndexes[2]).toInt();
        pressedKeys = data.substring(commaIndexes[2] + 1, commaIndexes[3]);
        maxSpeedValue = data.substring(commaIndexes[3] + 1, commaIndexes[4]).toInt();
        targetDetected = data.substring(commaIndexes[4] + 1, commaIndexes[5]).toInt();

        visionDeadzonePxX = data.substring(commaIndexes[5] + 1, commaIndexes[6]).toInt();
        visionDeadzonePxY = data.substring(commaIndexes[6] + 1).toInt();

        if (maxSpeedValue < 0) maxSpeedValue = 0;
        if (maxSpeedValue > 100) maxSpeedValue = 100;

        // Safeguards for deadzone received from YOLO.
        if (visionDeadzonePxX < 7) visionDeadzonePxX = 7;
        if (visionDeadzonePxY < 7) visionDeadzonePxY = 7;

        if (visionDeadzonePxX > 200) visionDeadzonePxX = 200;
        if (visionDeadzonePxY > 200) visionDeadzonePxY = 200;
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

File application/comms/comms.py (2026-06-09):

"""
ESP32 Serial Communications Module

Provides serial communication interface and keyboard input handling for the CSAimBot
robot control system. Facilitates bidirectional communication with the ESP32 microcontroller
and captures keyboard input for device operation.
"""

import platform
import time
from pynput import keyboard as pynput_kb
import serial


class SerialCommsModule:
    """
    This class manages serial communication with the ESP32 microcontroller.
    It provides methods to connect, send commands, receive responses, and disconnect.
    """

    def __init__(self, port=None, baud_rate=115200, timeout=0.05):
        """
        Initialize serial communication module with platform-specific default port.

        Args:
            port: Serial port name (auto-detected if None)
            baud_rate: Communication speed in bits/second (default: 115200)
            timeout: Read timeout in seconds (default: 2)
        """
        if port is None:
            currentSystem = platform.system()
            if currentSystem == "Windows":
                port = "COM5"
            elif currentSystem == "Darwin":
                port = "/dev/cu.usbserial-110"
            else:
                port = "/dev/ttyUSB0"

        self.port = port
        self.baud_rate = baud_rate
        self.timeout = timeout
        self.esp = None

    def connect(self):
        """
        Tries to establish a serial connection with the ESP32.
        Returns True if successful, False otherwise.
        """
        try:
            self.esp = serial.Serial()
            self.esp.port = self.port
            self.esp.baudrate = self.baud_rate
            self.esp.timeout = self.timeout
            self.esp.dtr = False
            self.esp.rts = False
            self.esp.open()
            time.sleep(1.5)
            if self.check_connection(self.esp, self.port):
                return True
            else:
                self.esp.close()
                return False
        except serial.SerialException as e:
            print(f"Connection error {self.port}\n{e}")
            return False

    def check_connection(self, esp, port):
        """
        Check if ESP32 is responsive by sending a test command and waiting for a specific response.
        Args:
            esp: Opened serial connection to ESP32
            port: Serial port name
        Returns:
            True if ESP32 is responsive, False otherwise
        """
        esp.reset_input_buffer()
        esp.write(f"ESP32-CHECK\r".encode("utf-8"))
        esp.flush()
        start_time = time.time()
        while time.time() - start_time < 5.0:
            if esp.in_waiting > 0:
                response = esp.readline().decode("utf-8", errors="ignore").strip()
                if response == "ESP32-READY":
                    print(f"Connected on {port}.")
                    return True
        print(f"Connection error {port}: No response from ESP32.")
        return False

    def send_command(self, command):
        """
        Encode and send command to ESP32. Appends carriage return for protocol.

        Args:
            command: Command string to send
        """
        if self.esp and self.esp.is_open:
            text_to_send = f"{command}\r".encode("utf-8")
            self.esp.write(text_to_send)
            self.esp.flush()
        else:
            print("Port closed. Unable to send command.")

    def get_response(self):
        """
        Read response from ESP32.

        Returns:
            Response string if available, None otherwise
        """
        if self.esp and self.esp.is_open:
            response = self.esp.readline().decode("utf-8", errors="ignore").strip()
            if response:
                return response
            return None
        else:
            print("Port closed. Unable to read response.")
            return None

    def disconnect(self):
        """Close the serial port if open."""
        if self.esp and self.esp.is_open:
            self.esp.close()
            print("Port closed successfully.")
        else:
            print("Port already closed or not yet opened.")


def comms_worker(conn):
    """
    Manage multiprocess communication between GUI, ESP32, and keyboard input.

    Runs in a separate process and handles command dispatch to ESP32,
    response reception, and keyboard state transmission back to GUI.

    Args:
        conn: multiprocessing.Connection object for IPC
    """
    esp = SerialCommsModule()
    keyboard = KeyboardInputModule()
    last_keys = ""
    last_send_time = 0.0
    is_connected = False
    running = True
    pressed_keys_set = set()  # Track which keys are currently pressed
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

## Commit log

2026-02-27 optimization
    - trying to optimize and eliminate CPU usage (RAM) in bettercam->YOLO chain using cupy
2026-02-28 optimized chain
    - Export the .engine file locally
    - TO BE TESTED:
    nvidia_gpu=True/False flag in bettercam (torch.from_dlpack) to avoid CPU,RAM and PCIE data transfer (maybe faster on lower end CPU)
2026-03-01 Full GPU chain
    bettercam -> CupyArray -> GPU tensor -> Formatted GPU tensor -> model
    *might be faster sometimes from CPU/GPU implementation
2026-03-01 Dodany wstępny kosztorys
    [Kosztorys ZSD.xlsx]
2026-03-01 Wstępny kosztorys
    [Kosztorys ZSD.xlsx]
2026-03-01 Changed button to avoid turning capturing the screen while typing commands. Added source for key codes
2026-03-06 Initial version of the electrical system schematic /w ANDRZEJRASCAL
    Added the first version of the electrical system schematic for the project.
    This version includes the basic structure of the electrical connections and main components.
    Further updates and improvements will be added in the next revisions.
    MADE WITH ANDRZEJRASCAL
    [CS_AIMBOT_v1.fzz]
2026-03-08 Części robota - part 1
    [Enkoder.stl, Profil_T-Slot_2020_400mm.stl, Szyna_MGN12_400mm.stl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]
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2026-03-11 Części robota - part 2
    [Nema_17_23mm.stl, Nema_23_Dual_Shaft.stl]
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2026-03-12 Części robota - prototyp chwytaka
    [Chwytak_Fin_Ray_Prototypowy.stl]
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2026-03-13 Corrected version of encoders
    Corrected wiring
    [CS_AIMBOT_v2.fzz]
2026-03-14 Added TCP communication module that will be used for communicating with ROS. I tried my best with error handling so hopefully it works and is error-proof.
    [comms.py]
2026-03-14 Potential fix for pull request finding
    [comms.py]
2026-03-15 simulation setup
    [corexy.urdf.xacro, properties.xacro]
2026-03-15 Extend urdf model
    [corexy.urdf.xacro, properties.xacro]
2026-03-15 Części robota - part 3
    [GT2_20T_Rolka_Gladka.stl, GT2_20T_Rolka_Zebata.stl]
2026-03-15 Added support for rails
    [corexy.urdf.xacro, properties.xacro]
2026-03-16 collision tags
    [corexy.urdf.xacro, properties.xacro]
2026-03-16 First gazebo launch
    [corexy.urdf.xacro, macro.xacro, properties.xacro]
2026-03-17 YOLO26n (BETA 2.0 version of dataset)
    - implemented training module
    - added labeled dataset (version BETA 2.0 [~3400 elements])
    - performed training of yolo26n on dataset
    - performed benchmarks on trained model (Beta_v2/benchmark.txt)
    [results.csv]
2026-03-17 Części robota - part 4
    [Listwa_Zebata_Serwo.stl, Solenoid.stl, Sprzeglo_8x5.stl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]
2026-03-18 Basic corexy gazebo control
    [corexy.urdf.xacro, motor_controllers.yaml]
2026-03-19 Części robota - prototyp chwytaka z ząbkami
    [Chwytak_Fin_Ray_Prototyp_Zabki.stl]
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2026-03-22 Części robota - part 5
    [Mocowanie_Wozek_Lewy.stl, Mocowanie_Wozek_Prawy.stl, Podstawa_Rolki.stl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]
2026-03-23 Added corexy urdf model with stl meshes
    [corexy.urdf.xacro, macro.xacro, monter_lewy.stl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]
2026-03-23 added control loop
    [real_corexy.xacro]
2026-03-24 YOLO26n (BETA 3.0 version of dataset)
    - added labeled dataset (version BETA 3.0 [6000 elements])
    - performed training of yolo26n on dataset 3.0
    [results.csv]
2026-03-24 Części robota - part 6
    [Chwytak.stl, Koncowka_Solenoida.stl, Krancowka.stl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]
2026-03-24 Model ze złożonym robotem - v1
    [Zlozenie_Robota.stl]
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2026-03-30 Added linux support
    - changed tkinter for DearPyGui (much faster when displaying graphs and other windows, for future features)
    - added CamraProvider class for linux compatibility
    - changed threading to multiprocessing to avoid GIL in python (changed from multi threads to multi system processes, prepearing for esp32 communication)
    - changed bettercam for zero-copy strategy (zero-copy on linux to be figured out (nvfbc), if not -> mss)
    - mss tested on windows (around 2.5 times slower than bettercam)
    [gui.py]
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2026-04-02 Added complete URDF robot model
    [Montaz_Robota.stl, chwytak.stl, links_macro.xacro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]
2026-04-07 new functionalities
    [real_corexy.xacro]
2026-04-08 World setup and improvements for nodes
    [corexy.sdf, mouse.stl, real_corexy.xacro]
2026-04-12 simple gui and updating project structure
    [Montaz_Robota.stl, chwytak.stl, corexy.sdf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]
2026-04-12 added calculation of nearest target (in pixels)
    - improved debug vision window
    - improved file structure
    - added choice of targets (sometimes model dont recognize CT as T and T as CT (especially from the back))
    [results.csv]
2026-04-15 Revert "Merge remote-tracking branch 'origin/main' into app"
    This reverts commit 9580157e98283f316e68bb176663914a8e5cca39, reversing
    changes made to 7a7941ed14344b7cc68c5532159d7535f264f9cd.
    [Chwytak.stl, Koncowka_Solenoida.stl, Krancowka.stl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]
2026-04-17 Fixed slider and icons, added MacOS compatibilty
    [gui.py]
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2026-04-20 performed training on betav4 dataset
    >10000 photos in dataset - OK
    > 95% mAP50 - OK
    TO BE DONE:
    - recoil compensation
    - starting simulation as an independent process
    - starting comms with esp32 as an independent process
    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
    [results.csv]
2026-04-20 Add communication worker and update GUI to handle ESP32 connection and keyboard input
    [CS_AIMBOT_v1.fzz, CS_AIMBOT_v2.fzz]
2026-04-21 Fixed simulation
    [Montaz_Robota.stl, chwytak.stl, corexy.sdf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]
2026-04-21 update to simulation
    - simplified simulation startup
    - fixed sim gui to use global env (not docker one)
    - updated requirements
    [gui.py]
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2026-04-22 added docker compose for linux and gui fixes
    [gui.py]
2026-04-28 Assembly 25.04 and file remenagment
    [Budget_ZSD_PL.xlsx, CS_AIMBOT_v1.fzz, CS_AIMBOT_v2.fzz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]
2026-04-29 Revert "Merge pull request #63 from ZSD-CSAimBot/assembly_and_app"
    This reverts commit 23ab185b99f3cbc1863a5355c15557b15fb002b8, reversing
    changes made to 01c22ccf9ccd147ce8e9e45a87c0e6f60923c333.
    [CS_AIMBOT_v1.fzz, CS_AIMBOT_v2.fzz, Chwytak_Fin_Ray_Prototyp_Zabki.stl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]
2026-04-29 Reapply "Merge pull request #63 from ZSD-CSAimBot/assembly_and_app"
    This reverts commit 5d26add8e72b815a14517f55b096c453aa7395c6.
    [Budget_ZSD_PL.xlsx, CS_AIMBOT_v1.fzz, CS_AIMBOT_v2.fzz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]
2026-04-29 Revert "Reapply "Merge pull request #63 from ZSD-CSAimBot/assembly_and_app""
    This reverts commit 22e739fd47b86095a2de89f0a6d32a86d0958231.
    [CS_AIMBOT_v1.fzz, CS_AIMBOT_v2.fzz, Chwytak_Fin_Ray_Prototyp_Zabki.stl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]
2026-04-29 Reapply "Reapply "Merge pull request #63 from ZSD-CSAimBot/assembly_and_app""
    This reverts commit 309c2f3f0c56861efa8b63921600a6b3f9a983b6.
    [Budget_ZSD_PL.xlsx, CS_AIMBOT_v1.fzz, CS_AIMBOT_v2.fzz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]
2026-04-29 Improve serial comms and refactor firmware pins
    Fixed comms
    [comms.py, gui.py, main.ino]
2026-04-30 Fixed bugs in simulation and changed fonts in sim gui
    [corexy.sdf, real_corexy.xacro]
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2026-05-04 comments in english, small fixes
    - bug with opening/closing simulation [TODO]
    [comms.py, gui.py, main.ino]
2026-05-05 fixing bug with sim closeing after merge
    #69
    [gui.py]
2026-05-08 Assebly of 07.05
    Finished hardware:
    - fixed solenoid
    - new gripper
    - better Z motor
    Some improvements of control system:
    - homing
    - added range of motion
    [main.ino]
2026-05-09 Uploading updated and improved models
    [Chwytak_Plaski_Bok.stl, Mocowanie_Wozek_Lewy.stl, Mocowanie_Wozek_Prawy.stl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]
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2026-05-11 Adding a box model for electronics
    [Montaz_Pudelko.stl, Pudeklo_Zasilacz.stl, Pudelko_DM556.stl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]
2026-05-12 Fixed X and Y
    [comms.py, gui.py, main.ino]
2026-05-12 Fixed mixed X and Y axis (for sure this time)
    [gui.py, main.ino]
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2026-05-13 Centering and Z setting
    - Home and center buttons in GUI
    - Fixed coordinates iin GUI
    - Fixed a issiue where if only one motor was working speed was slower
    - Minor fixes
    [comms.py, gui.py, main.ino]
2026-05-14 ELECTRONIC_SCHEME_FINAL_VERSION
    ELECTRONIC_SCHEME_FINAL_VERSION
    [ELECTRONIC_SCHEME_FINAL_VERSION.fzz]
2026-05-15 Windows Installer, Environment Automation and Fixes
    # Simulation Integration, Installer & Production Build
    ## Simulation Migration (PyQt6 → DearPyGui)
    - Removed PyQt6 dependency entirely from the project (`requirements.txt`, `build.spec`, all imports).
    - Replaced `sim_gui.py` (PyQt6 window) with `sim_worker.py` — a headless background process controlled via `multiprocessing.Pipe`.
    - Created a dedicated **Simulation** tab in the main DearPyGui interface with full robot control panel:
    - **D-pad** (8-directional movement + center) with keyboard shortcut labels (Q/W/E/A/C/D/Z/S/X).
    - **Z-axis** control (pick up / put down mouse).
    - **Gripper** control (open / close).
    - **Mouse** co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
    [Montaz_Robota.stl, chwytak.stl, corexy.sdf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]
2026-05-15 Resolves #80 . Did not test on linux
    [gui.py, mouse_blocker_worker.py]
2026-05-16 Fixed text color and added evdev to requirements.txt
    [gui.py]
2026-05-16 fixed Linux mouse blocker
    [mouse_blocker_worker.py]
2026-05-18 Adding updated and fixed models
    [DM556.stl, ESP32.stl, ESP32_Terminal_Adapter.stl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]
2026-05-19 added plotting X/Y pos., and dist to target
    also added new sim icon
    and minor fix in sim_worker.py to print out the errors
    [gui.py]
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2026-05-19 comments and simple fixes
    [gui.py, main.ino]
2026-05-19 Fixed Dist to target plot
    [gui.py]
2026-05-19 calibration
    connected calibration into main gui
    fixed some small issues
    [comms.py, gui.py, main.ino]
2026-05-22 Reworked calibration
2026-05-30 Adding the final version of the model
    [Montaz_Robota.stl, Pudelko_Napis_Bok.stl, Pudelko_Napis_Gora_Lewa.stl]
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2026-05-31 Fix typos in assembly instructions
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2026-06-06 Added PID edit in settings, minor fixes
    [gui.py, main.ino]
2026-06-07 Fixed PID, fixed CSGO sens, added min values
    [gui.py, main.ino]
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2026-06-09 File cleanup and renamed files
    [Budget_ZSD_PL.xlsx, CS_AIMBOT_v1.fzz, CS_AIMBOT_v2.fzz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]
2026-06-09 Updating models
    [Mocowanie_Wozek_Lewy.stl, Mocowanie_Wozek_Prawy.stl]
